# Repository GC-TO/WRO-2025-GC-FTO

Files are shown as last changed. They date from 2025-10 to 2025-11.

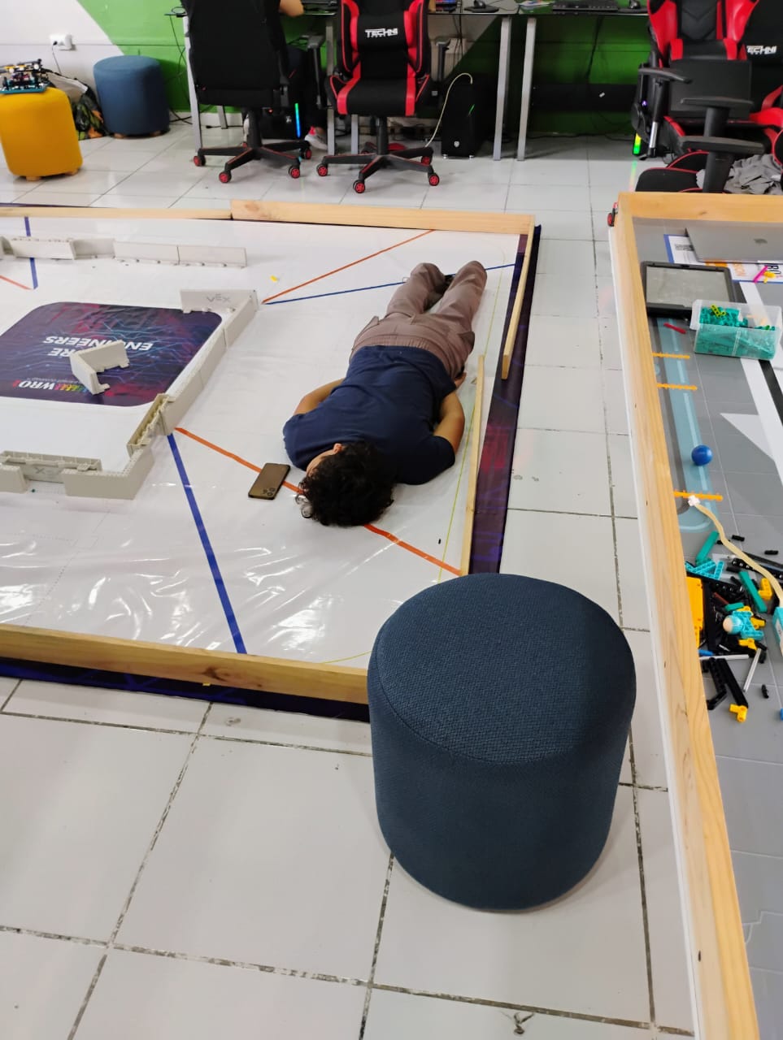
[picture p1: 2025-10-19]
Photo E/XD Photos/Fotos XD (2).jpeg

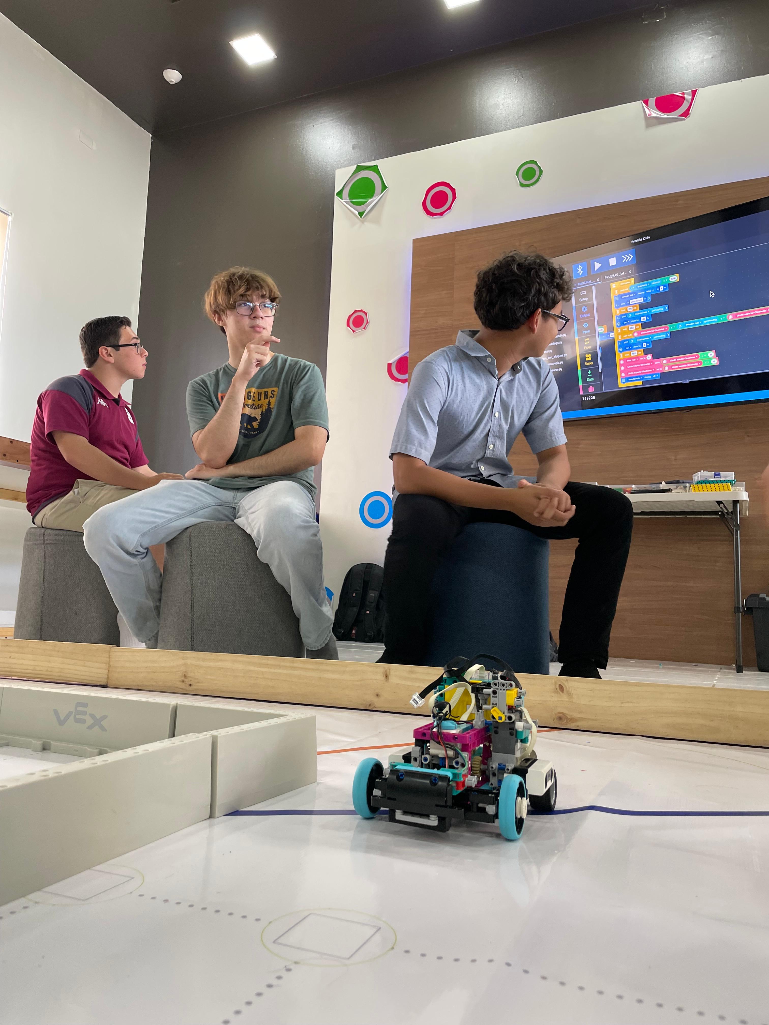
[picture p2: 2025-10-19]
Photo E/Group Photo/Fotos eqüipo (1).jpeg

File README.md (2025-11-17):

# Future TO - Future Engineers
### World Robot Olympiad 2025

This repository contains all our hard work and resources necessary to build **'Tigresa del Oriente'** (Eastern Tigress), the autonomous robot developed by Team Future TO for the World Robot Olympiad Future Engineers category.

---

## Table of Contents
- [Team Information](#team-information)
- [About the Competition](#about-the-competition)
- [General Description of the Robot](#general-description-of-the-robot)
- [Software Architecture](#software-architecture)
  
---

## Team Information

**Team Name:** Future TO  
**Country:** El Salvador 🇸🇻  
**Coach:** Sergio Cuellar

### Team Members:
- **Manuel Vásquez** - Team Leader, Programming and Control Systems
- **Antonio Borst** - Mechanical Design and Construction
- **Daniel Salazar** - Technical Documentation and Compliance

  

---

## About the Competition

The Future Engineers category challenges teams to design self-driving robots capable of navigating complex circuits autonomously. Our robot must complete two main challenges:

### Open Challenge
- Complete three laps around a circuit
- Navigate with randomly determined: circuit size, starting position, and direction of travel
- Detect and follow blue/orange lines to determine direction (clockwise/counterclockwise)

### Obstacle Challenge
- Navigate a fixed circuit layout
- Avoid randomly placed obstacles (red and green blocks)
- Make real-time decisions based on obstacle color and position

---

## General Description of the Robot

**Tigresa del Oriente** is built primarily using LEGO Technic components, enhanced with third-party sensors and processing units for advanced autonomous capabilities.

### Key Design Features:

**Differential Drive System**
- Utilizes LEGO Technic differential piece
- Allows wheels to rotate at different speeds during turns
- Provides stable and controlled movement through tight corners
- Distributes torque efficiently between rear wheels

**Steering System**
- Inspired by Haltenberger Linkage design
- Features gear reduction for enhanced precision
- Example: 10° motor rotation = 1° tire rotation (10:1 ratio)
- Minimizes the impact of minor motor positioning errors

**Autonomous Navigation**
- IMU-based precise turning (not time or distance-based)
- Multi-sensor fusion for environment perception
- Real-time decision making for obstacle avoidance
- Continuous repositioning to maintain centered trajectory



---

## Hardware Components

### Main Components
| Component | Model | Quantity | Purpose |
|---|---|---|---|
| Main Controller | LEGO Mindstorms Inventor Hub | 1 | Central processing and motor control |
| Battery | Inventor Hub Battery | 1 | Primary power source |
| Drive Motor | LEGO Mindstorms Motor | 1 | Forward/backward movement |
| Steering Motor | LEGO Mindstorms Motor | 1 | Front wheel orientation |

### Sensors and Perception
| Sensor Type | Model | Quantity | Purpose |
|---|---|---|---|
| Color Sensor | LEGO Mindstorms | 1 | Floor line detection (blue/orange) |
| Ultrasonic Sensors | LEGO Mindstorms | 2 | Lateral wall distance measurement |
| Ultrasonic Sensors | Arduino | 3 | Precise distance measurement (1 front, 2 at 45°) |
| AI Camera | HuskyLens | 1 | Object and color detection at distance |
| IMU | Built into Inventor Hub | 1 | Precise angle measurement for turns |

### Additional Electronics
| Component | Purpose |
|---|---|
| LMS-ESP32 Board | Sensor data processing and Hub communication |
| LED Lighting System | Controlled illumination for camera stability |
| AAA Battery Pack (6x) | Independent power for lighting system |
| Relay Module | Lighting control via ESP32 |
| Optocoupler | Safe relay activation |

---

## Software Architecture

### Programming Languages & Platforms
- **Main Program:** Python 3 with Pybricks (LEGO Inventor Hub)
- **Sensor Processing:** Python with Thonny (LMS-ESP32)

### Code Structure

**LEGO Inventor Hub (Main Controller)**
```
├── Motor Control Functions
│   ├── Steering calibration and control
│   ├── Drive motor management
│   └── IMU-based precise turning
│
├── Sensor Reading Functions
│   ├── Color sensor (HSV processing)
│   ├── Ultrasonic sensors (lateral positioning)
│   └── ESP32 data reception (PUPRemote)
│
├── Navigation Logic
│   ├── Open Challenge: Line detection and repositioning
│   ├── Obstacle Challenge: Object detection and avoidance
│   └── Continuous feedback loop
│
└── Main Execution Loop
    ├── Sensor data collection
    ├── Decision making
    └── Action execution
```

**LMS-ESP32 (Sensor Coprocessor)**
```
├── Sensor Data Acquisition
│   ├── Ultrasonic sensors (I²C)
│   ├── HuskyLens camera (UART)
│   └── Lighting system control
│
├── Data Processing
│   ├── Filter and validate readings
│   ├── Convert to LEGO-compatible format
│   └── Package for transmission
│
└── PUPRemote Communication
    └── Send processed data to Inventor Hub
```

### Key Programming Features

**Modular Design**
- Independent functions for each robot behavior
- Easy maintenance and debugging
- Clear separation of responsibilities

**Quasi-Asynchronous Operation**
- Multiple tasks appear to run simultaneously
- Sensor reading doesn't block movement
- Continuous decision-making cycle
- Rapid response to environmental changes

**Calibration Systems**
- Automatic steering calibration on startup
- Color sensor HSV threshold configuration
- Battery voltage monitoring (79% performance threshold)

**Navigation Algorithms**

*Open Challenge:*
- Calculate distance ratio: R = Right Distance / Left Distance
- Tolerance range: 0.58 ≤ R ≤ 1.67
- Corrective steering when outside tolerance
- Line detection triggers turn sequences

*Obstacle Challenge:*
- HuskyLens detects block color (red/green)
- Execute appropriate evasive maneuver
- Controlled turn -> advance -> counter-turn -> recenter
- Ultrasonic verification of centered position

---

## Contact

For questions or collaboration opportunities:
- **Team Email:** [gamechanger.info2022@gmail.com]
- **Coach:** Sergio Cuellar

---

**Team Future TO** | El Salvador 🇸🇻 | WRO 2025 Future Engineers

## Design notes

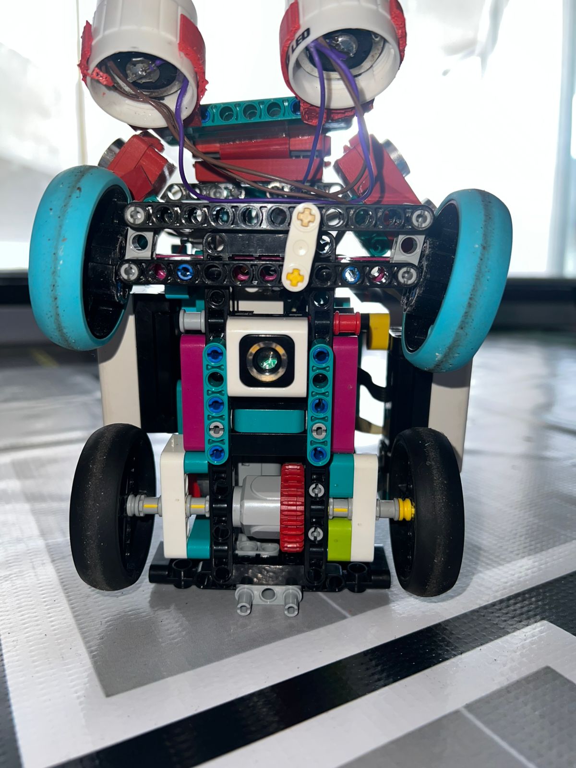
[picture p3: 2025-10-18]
Photos WRO/TO6/TO6 (7).jpeg

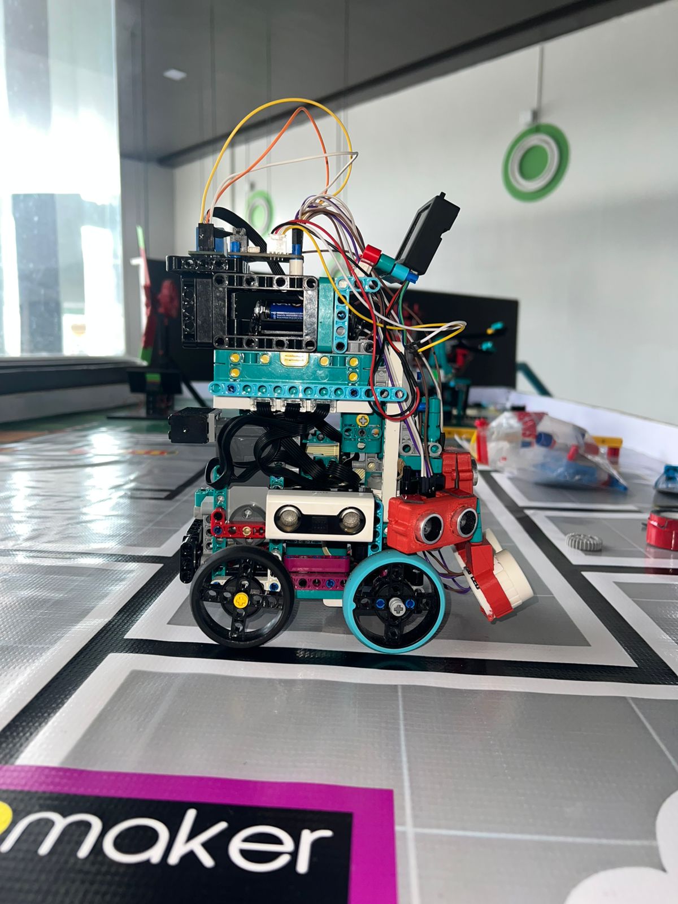
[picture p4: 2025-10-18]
Photos WRO/TO6/TO6 (19).jpeg

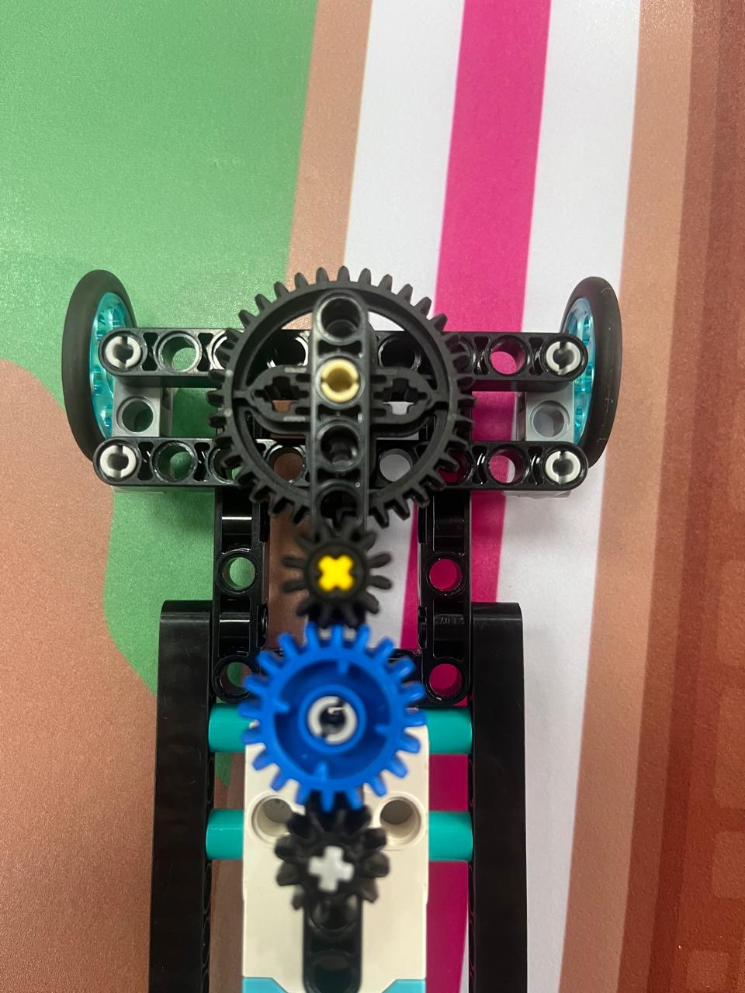
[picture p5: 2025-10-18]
Photos WRO/TO1/TO1 .jpeg

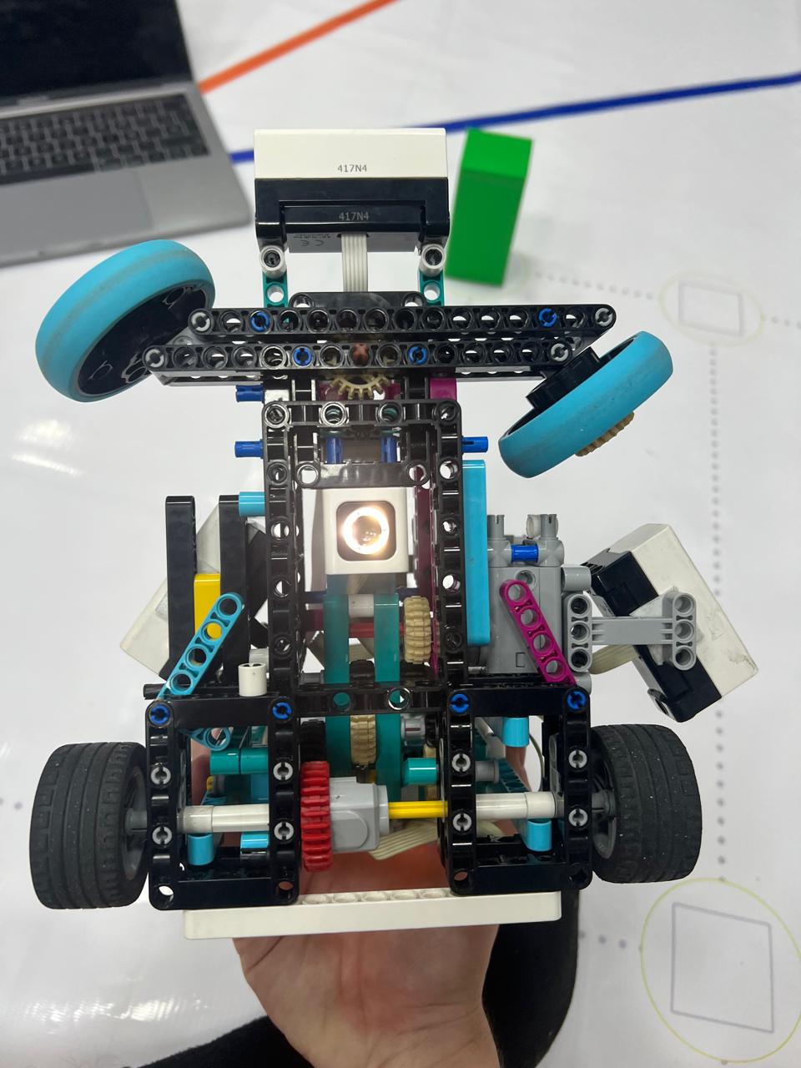
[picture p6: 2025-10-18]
Photos WRO/TO3/TO3 (3).jpeg

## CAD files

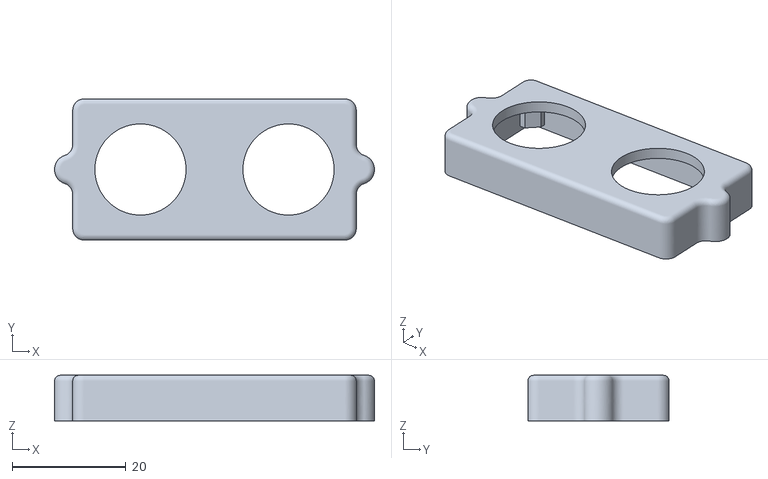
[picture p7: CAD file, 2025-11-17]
Materials/3D Models/Casing for the ultrasonic sensors/top.stl
56.2 x 24.8 x 8.00

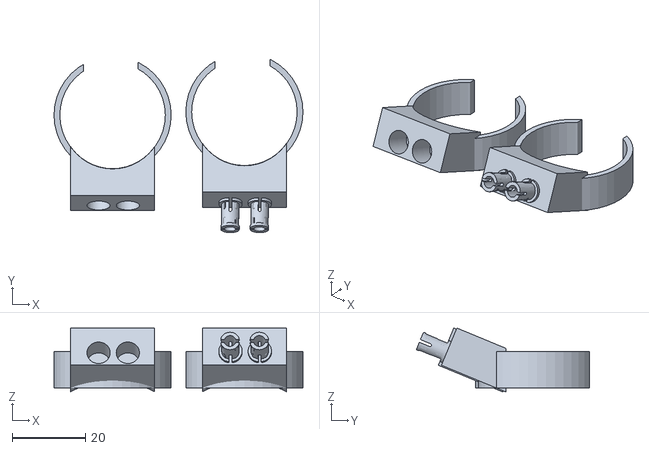
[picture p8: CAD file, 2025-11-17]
Materials/3D Models/Super Curcan (1).stl
68.0 x 47.3 x 17.5

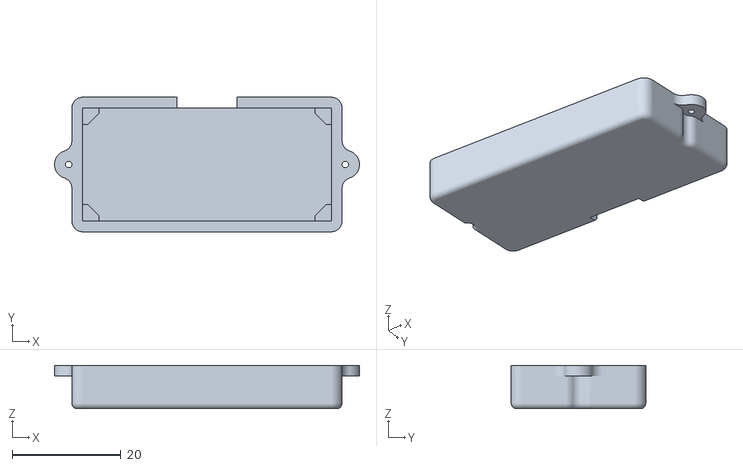
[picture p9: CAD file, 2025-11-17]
Materials/3D Models/Casing for the ultrasonic sensors/bottom_v2.stl
56.2 x 24.8 x 8.00

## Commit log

2025-08-01 Create A2
    Es la segunda actuación del código general
2025-10-27 Implement car navigation and obstacle avoidance logic
    Add functions for car navigation and obstacle avoidance using IMU and distance sensors.
2025-10-27 Delete A5
    Me equivoqué de archivo
2025-11-15 Final update of obstacle and open challenge implementations
    This file contains the implementation of obstacle and open challenges for a robotic car using the PyBricks library, including sensor initialization, movement functions, and obstacle detection logic.
2025-11-17 Materials and plans used
    Including the connection diagrams for the component interconnections, along with flow diagrams for both the Open and Obstacle Challenges, as well as the program logic for each.
2025-11-17 A Lego-compatible light base
    This is the base where the lights are situated, it is a 3D model file.
    :)
    [Super Curcan (1).stl]
2025-11-17 Case for the ultrasonic sensor
    The same as the title
    [bottom_v2.stl, top.stl]
2025-11-17 Update sensor details in README
    Updated sensor information in the README to reflect changes in sensor types and models.
